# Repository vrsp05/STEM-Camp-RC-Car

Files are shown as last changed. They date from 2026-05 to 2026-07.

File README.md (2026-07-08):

# BYU STEM Camp RC Car

## About This Project

Built by Victor Santana, Jaime Mejia, and Dan Barry as a proposed 2026 workshop for the BYU STEM Camp, this project delivers a robust, low-cost, and low-latency RC car framework. It transforms a standard ESP32-CAM into a standalone web server, video streamer, and motor controller, all without requiring an external internet connection. This interactive experience is designed to inspire students and provide hands-on learning in embedded systems, IoT technology, microcontrollers, and real-time wireless networking.

## Features

* **Low-Latency Video:** Optimized firmware utilizing CIF (400x296) resolution and an adjusted 10MHz clock speed for good MJPEG streaming over a local network.
* **WebSocket System:** Fast response times for driving controls and camera tuning, ensuring the car reacts to your steering instantly.
* **Frictionless Connectivity:** Auto-broadcasting, password-free Wi-Fi Access Points (e.g., `BYU-Car-1`). Students connect and drive instantly.
* **On-the-Fly Tuning:** A sleek, mobile-friendly web dashboard featuring a D-Pad and live sliders to control Headlight brightness, Camera Contrast, and Exposure.

## The Map (How is it organized?)

The repository is organized into four top-level folders to separate documentation, firmware, physical parts, and the web dashboard:

```text
STEM-CAMP-RC-CAR/
├── docs/              # user guides, lesson plans, and troubleshooting
├── firmware/          # ESP32/Arduino source code, configs, and builds
├── hardware/          # 3D-print STL, PCB files, schematics, and BOM
└── web_interface/     # dashboard UI (HTML/CSS/JS) and client assets
```

- **docs/**: Step‑by‑step manuals, programming guides, setup instructions, classroom materials, and troubleshooting notes to build and operate the car.
- **firmware/**: All source code and build artifacts for the ESP32 firmware (sketches, header/config files, build scripts, and CI files). Flashable binaries and board configuration live here.
- **hardware/**: CAD and STL files for 3D printing, PCB design and Gerber/board files, circuit schematics, wiring diagrams, and the bill of materials (BOM).
- **web_interface/**: The mobile‑friendly dashboard — HTML, CSS, JavaScript, assets, and client‑side WebSocket code used to view live video and control the car from a browser or phone.

## The Shopping List (Hardware Requirements)

To build this car, you will need a mix of custom parts and standard robotics electronics. Here is the detailed breakdown:

| Component | Quantity | Purchase Link |
| :--- | :--- | :--- |
| **ESP32-CAM (OV2640 camera)** | 1 | [DigiKey](https://www.digikey.com/short/w14d0qp4) |
| **DRV8833 Motor Controller** | 1 | [Amazon](https://a.co/d/00hcKW4g) |
| **8-Pin Female-to-Male Headers** | 2 | [DigiKey](https://www.digikey.com/short/5r3mm5rb) |
| **6-Pin Male-to-Male Headers** | 1 | [DigiKey](https://www.digikey.com/short/bth0dmv4) |
| **TT DC Gearbox Motors** | 4 | [Amazon](https://a.co/d/0djxPo1a) |
| **Rubber Wheels (for TT Motors)** | 4 | [Amazon](https://a.co/d/0djxPo1a) |
| **T-Brackets** | 4 | [/3d_prints/](hardware/3d_prints/T-Bracket_Mount.stl) |
| **Camera Mount** | 1 | [/3d_prints/](hardware/3d_prints/Camera_Mount.stl) |
| **Headlight Mount** | 1 | [/3d_prints/](/hardware/3d_prints/) |
| **6-32 x 1/4" Mounting Screws** | 8 | [Amazon](https://a.co/d/0eqBX8dm) |
| **Custom PCB Chassis** | 1 | [/electronics/](/hardware/electronics/RC_Car_PCB_v4.zip) |
| **4-AA Battery Holder** | 1 | [DigiKey](https://www.digikey.com/short/vzvpw4tr) |
| **Power Switch (SLW-1276864-4A-D)** | 1 | [DigiKey](https://www.digikey.com/short/3592nqjh) |
| **AA Batteries** | 4 | [Amazon](https://a.co/d/0iRKMYl3) |
| **Zip Tie** | 1 | [Amazon](https://a.co/d/0diwe9JH) |
| **Small Foam / Cardboard Rectangle** | 1 | [Amazon](https://a.co/d/09obGXU5) |

**Total estimated price:** $50-$80

## The Instructions (How do I build it?)

To build, program, and drive your car, you just need to download this repository and follow the step-by-step guides. You do not need to figure out how to build it from scratch, everything is already mapped out for you:

**Step 1: Download the Files (Fork and Clone)**

Before doing anything, you need to save a copy of all these project files to your own computer.

   * Click the **Fork** button at the top right of this GitHub page. This creates a safe copy in your own account so you can make changes without breaking the original project.
   * Open your computer's terminal and clone your new copy by typing:
      ```bash
      git clone https://github.com/vrsp05/STEM-Camp-RC-Car.git

      cd STEM-Camp-RC-Car
      ```

**Step 2: Set Up Your Computer**

   * **File:** [environment_setup.md](/docs/environment/environment_setup.md)
   * **What it does:** This guide shows you exactly how to install the Arduino IDE on your computer, add the ESP32 chip definitions, and make sure your computer can talk to the car's brain over a USB cable.

**Step 3: Assemble the Hardware**

   * **File:** [assembly_guide.pdf](/docs/assembly_docs/assembly_guide.pdf)
   * **What it does:** This is your physical instruction manual. It has clear pictures and step-by-step directions showing you how to solder the electronics to the custom PCB chassis, mount the four yellow gearbox motors using your screws, and attach the wheels.

**Step 4: Program the Brain**

   * **File:** [programming_guide.md](/docs/programming/programming_instructions.md)
   * **What it does:** This guide teaches you how to open the code, give your car a unique Wi-Fi network name, and safely flash the firmware onto the ESP32-CAM using the correct settings so it is ready to drive.

## Credits

**Hardware & Custom PCB Design:**
- **Dan Barry** and **Jaime Mejia** for engineering the custom PCB and assembling the physical hardware of the car.

**Software & Inspiration:**
This project builds upon excellent educational resources from the community:
- [ESP32-CAM Streaming with Motor Control](https://www.youtube.com/watch?v=7I4SnUXxUR0&t=2s) by Jeevan Jee
- [Simple Circuits Tutorial](https://www.youtube.com/watch?v=Du1UvHnD-ZM) by Simple Circuits
- [ESP32-CAM Car Robot Web Server](https://randomnerdtutorials.com/esp32-cam-car-robot-web-server/) by Random Nerd Tutorials
- [RoboArmy Project](https://youtu.be/YqQc_Sm9vlA) by RoboArmy

---

Developed for the BYU STEM Camp (2026).

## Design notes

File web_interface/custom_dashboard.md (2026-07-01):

# Customizing the Dashboard

If you want to customize the look of your car's driving dashboard (change colors, adjust button sizes, or add new controls), do **not** edit the C++ files directly right away!

Inside this repository, you will find a folder called `web_interface` containing an `index.html` file. This is your **UI Sandbox**. Because the structure (HTML) and the styling (CSS) are both inside this single file, testing new designs is incredibly easy.

## How to Test and Save Your Changes

1. **Open the Sandbox:** Double-click `index.html` to open it in your web browser. 
2. **Edit the Code:** Open the exact same file in any text editor (like VS Code or Notepad) and make your changes.
3. **Test Instantly:** Refresh your web browser to see your changes instantly. *(Note: You will not see the live video feed yet, but you will see all your new colors and buttons!)*
4. **Copy Your Work:** Once your new dashboard looks perfect, select everything and copy the entire contents of your customized `index.html` file.
5. **Flash to the Car:** Open `firmware/rc_car_main/index.h` and carefully paste your new code inside the raw string literal to permanently flash it to the car.

## 3 Fun Challenges to Try

Before you copy your final code over to the car, try completing these three challenges inside your `index.html` file!

### Challenge 1: Change the Background Color
Right now, the dashboard has a dark blue background. Let's make it your favorite color!
* Look inside the `<style>` section near the top of the file.
* Find the line that starts with `body { background-color: var(--byu-blue);`. 
* Change `var(--byu-blue)` to a simple color name like `black`, `green`, or `orange`. Save the file and refresh your browser!

### Challenge 2: Change the Button Symbols to Words
Right now, the driving buttons use shapes like ▲ and ■. Want to make them say words instead? 
* Scroll down past the styles until you find the HTML code for the buttons (look for lines like `<button id="btn-fwd">▲</button>`).
* Delete the ▲ symbol and type in a word like "FORWARD" or "GAS". Save the file and refresh your browser.

### Challenge 3: Make the D-Pad Bigger
If the steering buttons are too small for your thumbs, you can scale them up!
* Go back up to the `<style>` section and look for the `.controls button {` line. 
* Find `padding: 20px 0;` and change the `20` to `35`.
* Find `font-size: 1.2em;` and change the `1.2` to `2.0`. 
* Save your file, and see how your giant buttons look on the screen!

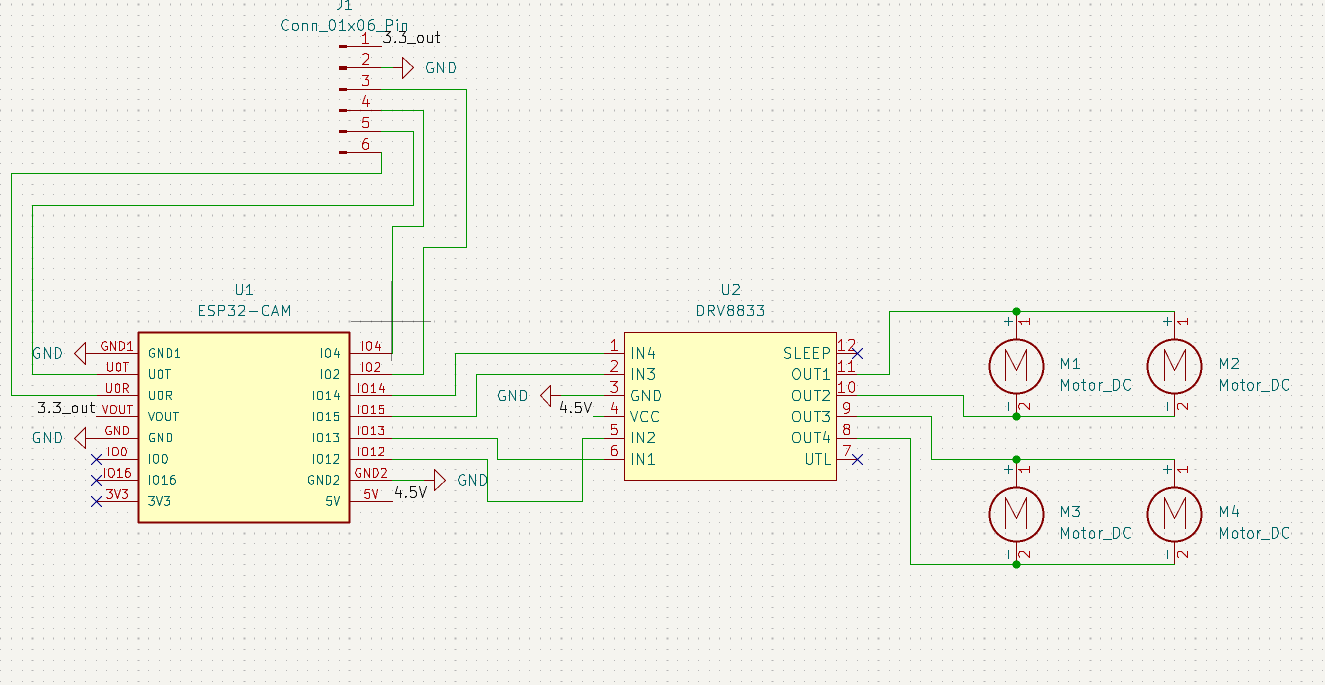
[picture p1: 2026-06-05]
hardware/electronics/STEM Camp RC Car Schematic.png

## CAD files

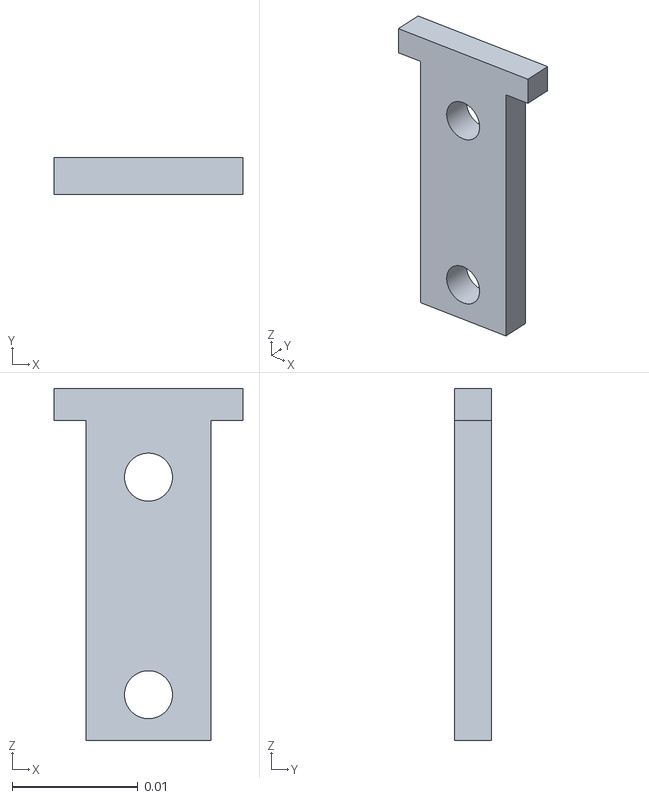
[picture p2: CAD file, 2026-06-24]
hardware/3d_prints/T-Bracket_Mount.stl
0.015 x 0.00292 x 0.0279

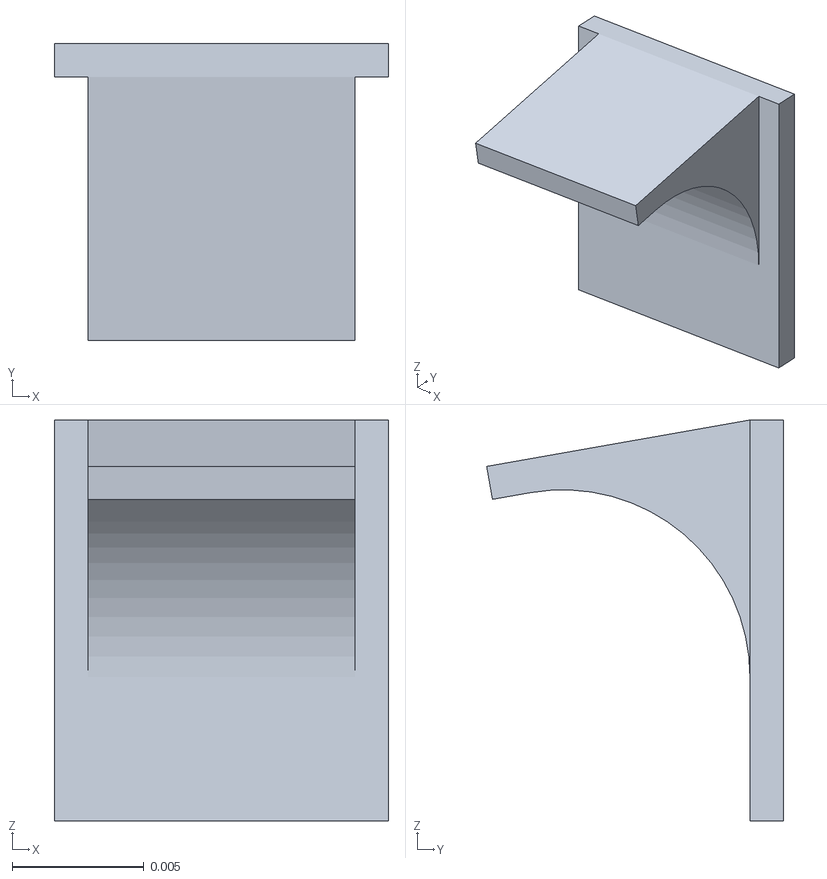
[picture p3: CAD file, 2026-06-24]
hardware/3d_prints/Camera_Mount.stl
0.0127 x 0.0113 x 0.0152

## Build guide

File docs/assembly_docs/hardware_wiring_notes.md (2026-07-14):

# Hardware & Wiring Notes

If you are building the car using the custom STEM Camp PCB, this guide explains exactly how the electronics connect and the number one physical mistake to avoid when building your drivetrain.

## Wiring Guide

The custom PCB handles all the complicated power routing for you, but it is helpful to know exactly how the car's brain talks to the wheels. The ESP32-CAM sends signals to the motor controller using these specific pins:

* **Left Motors (Channel A):** Controlled by GPIO 14 and GPIO 15
* **Right Motors (Channel B):** Controlled by GPIO 13 and GPIO 12
* **Camera LED Flashlight:** Controlled by GPIO 4

## Crucial Assembly Warning: The "Mirror Effect"

When you build a 4-wheel drive car, you have front motors and back motors. Because of how they fit into the plastic frame, the front and back motors are physically facing opposite directions. They are "mirrored."

**The Problem:** If you solder the wires to the front motors and the back motors exactly the same way, the front wheels will spin forward, but the back wheels will spin backward. The car will fight against itself and will not move properly.

**The Fix:** You must solder the wires on the back motors "backwards" compared to the front motors so all four wheels push in the exact same direction. 

* If your **Front** motors (M1 & M3) have the **Red** wire on the + pin and the **Black** wire on the - pin.
* Your **Back** motors (M2 & M4) must have the **Black** wire on the + pin and the **Red** wire on the - pin. 

Always double-check your motor wiring before you screw the chassis completely together!

## Hardware Quirks: Motor Speeds

Not all yellow TT motors are created equal! If one of your cars is much faster than the others, check the motor colors. 

* **Dull Yellow Motors:** These typically have a **1:48 gear ratio**. They are built for high speed. 
* **Bright Yellow Motors:** These typically have a **1:120 gear ratio**. They are built for heavy pushing power and will drive much slower. 

Always try to match the exact same motor colors when building a single car. If you mix a dull yellow motor with a bright yellow motor, your car will constantly pull to one side and will not drive straight!

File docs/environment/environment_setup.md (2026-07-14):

# Setting Up Your Environment

Before we can teach the car how to drive, we need to teach your computer how to talk to the car's brain. To do this, we use a free program called the **Arduino IDE**.

## What You Need (Prerequisites)

Before opening any programs, make sure you have these items ready on your desk:

* **The Free Software:** Download and install the [Arduino IDE](https://www.arduino.cc/en/software) on your computer.
* **The Car's Brain:** Your ESP32-CAM board with the tiny camera attached.
* **The USB Adapter:** The ESP32-CAM cannot plug directly into a computer. You must plug it into the small USB programmer board (the motherboard "MB" adapter shield) first.
* **A Data-Sync USB Cable:** This is incredibly important. Many phone charger cables only provide power and cannot send data. You *must* use a cable that supports data transfer, or your computer will never see the ESP32.

## Step 1: Install ESP32 Board Support

1. Open the **Arduino IDE**.
2. Go to **Tools → Board → Boards Manager**.
3. Search for `ESP32` in the search box.
4. Find **"esp32 by Espressif Systems"** and select the **latest version**.
5. Click the **Install** button and wait for the installation to complete.

## Step 2: Download the Remote Control Dictionary (WebSockets)

The ESP32 dictionary we just installed knows how to use basic Wi-Fi, but it doesn't know how to connect to our custom digital steering wheel. We need to download a library to fix that.

1. **Open the Library Manager:** In the Arduino IDE, click on **Sketch** at the top of the screen, hover over **Include Library**, and click **Manage Libraries...** (You can also just click the little icon that looks like a stack of books on the left side of your screen).
2. **Search for WebSockets:** In the search bar of the new menu, type in exactly `WebSockets` and hit Enter.
3. **Find the Right Author:** Scroll through the list until you find the library named exactly **WebSockets**. Look closely at the small text underneath the title—it **must** say **by Markus Sattler**.
4. **Install It:** Select the latest version and click the **Install** button next to it. Once it says "Installed," you can close the Library Manager menu.

## Step 3: Tell the Computer Which Brain You Have

The dictionary we just downloaded is huge. It contains instructions for hundreds of different ESP32 chips! We need to tell the computer exactly which one you are holding in your hand.

1. **Open the Board Menu:** At the top of your screen, click on **Tools**, hover over **Board**, and then hover over the new **esp32** folder you just installed.
2. **Find the AI Thinker:** A massive list of boards will pop out. Scroll down through this list until you find the one named exactly **"AI Thinker ESP32-CAM"**.
3. **Select It:** Click on it! 

*Pro-Tip: You can double-check that you did it right by looking at the top left corner of your Arduino window. It should now say "AI Thinker ESP32-CAM".*

## Step 4: Pick the Right USB Door (Select the COM Port)

Your computer has several USB plugs, and it doesn't automatically know which one is holding the car's brain. We need to point it to the right "door" so they can talk.

1. **Plug It In:** Connect your ESP32-CAM (attached to its small programmer board) to your computer using your data-sync USB cable.
2. **Open the Menu:** In the Arduino program, click on **Tools** at the top of the screen.
3. **Find the Port:** Look down the menu list and hover over **Port**. 
4. **Select the Connection:** You should see an option pop up. If you are on Windows, it will look like `COM3` (or a higher number). If you are on a Mac, it will look like `/dev/cu.usbserial-....`. Click on it! 

*Pro-Tip: If you have a bunch of different ports listed and don't know which one is your car, or if the "Port" button is completely grayed out, don't panic! Check the **How to Find Your Port** section right below this to play detective.*

---

### How to Find Your Port (Windows & Mac)

If you are completely stuck on Step 3, you can use your computer's built-in tools to figure out exactly which port your car is plugged into.

**For Windows (Device Manager):**
1. Click the Windows Start button at the bottom of your screen, type **Device Manager**, and hit Enter.
2. Look down the list for a category called **Ports (COM & LPT)** and click the little arrow next to it to open it up.
3. You are looking for a device that says **USB-SERIAL CH340**, **CP210x**, or something similar.
4. Look at the number right next to it in parentheses (for example, `COM4`). That is your port number. Go back to the Arduino IDE and select that exact port.

**For Mac (System Report):**
1. Click the **Apple logo** in the very top left corner of your screen.
2. Click **About This Mac**, then click **More Info...**, and finally scroll down and click **System Report...**.
3. On the left side of the new window, look under the "Hardware" section and click on **USB**.
4. Look through the USB Device Tree for something named **USB to UART Bridge** or **CH340**. If you see it there, your computer successfully sees the car! Go back to the Arduino program and select the port that starts with `/dev/cu.usbserial`.

*(Note: If you do not see the device in your Windows Device Manager or your Mac System Report, your USB cable is likely a "charge-only" cable. Swap it out for a real data cable and try again!)*

---

**You Did It!**
Your computer is now fully set up and ready to code. You can close this guide, return to the **[main README](../../README.md)**, and follow the next steps to flash the brain and start driving!

## Troubleshooting (What if it doesn't work?)

Don't panic! Even professional engineers run into errors. Here is how to fix the most common computer bugs:

### 1. "My Port is Not Showing Up!"
* **The Cable Test:** 99% of the time, this happens because you are using a "charge-only" USB cable instead of a "data" cable. Try swapping out the cable!
* **The Connection Test:** Make sure the ESP32-CAM is pushed down firmly into the small programmer board.

### 2. "The Upload Keeps Failing!"
* **Check Your Brain:** Go back to **Tools > Board** and make absolutely sure you selected **"AI Thinker ESP32-CAM"**. 
* **The BOOT Button Trick:** Sometimes the brain is stubborn and won't accept the new code. While the code is uploading, physically press and hold the **BOOT** (or **IO0**) button on the small programmer board. This forces the chip to wake up and listen to the computer!

*(Note: It's also possible that you may have purchased a defective or low-quality ESP32. We recommend buying from DigiKey or other trustworthy sellers.)*

### 3. "My Camera Screen is Blank!"
* **The Ribbon Snap:** Check the tiny ribbon cable connecting the camera to the board. It needs to be pushed all the way in and locked down safely.
* **The MicroSD Trap:** If you have a little memory card (MicroSD card) plugged into the back of the ESP32-CAM, take it out! It completely blocks the live video from working.

*(Note: It's also possible that you may have purchased a defective or low-quality ESP32. We recommend buying from DigiKey or other trustworthy sellers.)*

### 4. "fatal error: WebSocketsServer.h: No such file or directory"
* **The Missing Library Error:** The computer is trying to build the remote control connection, but it doesn't have the instructions. Go back to **Step 2** and make absolutely sure you installed the **WebSockets by Markus Sattler** library using the Library Manager.

### 5. "The Upload Keeps Crashing / Hidden Baud Rate"
* **The Dev Module Trick:** Sometimes the computer tries to send the code too fast, which causes a crash. If you need to lower the upload speed (baud rate) but the Arduino IDE hides that option when you select the AI Thinker board, you can outsmart it. Change your board to **"ESP32 Dev Module"**. This is a generic profile that unlocks the hidden menus. Change your **Upload Speed** to **115200**, make sure **PSRAM** is **Enabled**, and try uploading again.

*(Note: It's also possible that you may have purchased a defective or low-quality ESP32. We recommend buying from DigiKey or other trustworthy sellers.)*

### 6. Still Stuck?
* **Ask an AI Helper:** If the Arduino program spits out a crazy red error message, you can copy that text and paste it into ChatGPT, Claude, or GitHub Copilot. Just ask the AI, "How do I fix this Arduino error?" and it will help translate the computer gibberish for you!

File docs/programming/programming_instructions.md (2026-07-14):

# BYU STEM Camp RC Car: Programming Guide

Welcome to the final step of your RC Car build. Right now, your car is just plastic, motors, and wires. In this guide, we are going to give it a brain.

The tiny computer on your car (called the ESP32-CAM) is incredibly special. It does not just hold code, it actually creates its very own Wi-Fi network! 

Here is how the magic works:
1. **The Code:** We will upload a file that teaches the brain how to drive.
2. **The Wi-Fi:** The brain will create a private Wi-Fi network just for your car.
3. **The Connection:** You will connect your phone to that network, turning your phone into the steering wheel and the video screen.

Let's get your car programmed and ready to race!

## Step-by-Step Setup

### 1. Name Your Car & Pick a Wi-Fi Channel

Before we put the brain into the car, we need to give it a unique identity. If all the cars in the room have the exact same Wi-Fi name, your phone will not know which one is yours, and you might accidentally connect to your friend's car.

We also need to pick a Wi-Fi **Channel**. Think of a channel like a lane on an invisible highway. If every single car in the camp tries to drive in the exact same lane, there will be a massive traffic jam and your live video may freeze. 

Here is exactly how to change your car's name and pick your highway lane in the code:

1. **Open the Code:** Open the Arduino IDE on your computer. Click **File > Open**, and open the main code file located inside your `firmware/rc_car_main` folder called `rc_car_main.ino`. 
2. **Find the Wi-Fi Name:** Scroll down near the top of the code until you see a line that sets the network name. It will look something like this:
   `const char *carSSID = "BYU-Car-0";`
3. **Change the Name:** Delete the words inside the quotation marks and type in your own custom name (for example: `"BYU-Car-1"` or `"Lightning"`). *Warning: Make sure you do not delete the quotation marks!*
4. **Find the Channel:** Right below your name, look for the line that sets the Wi-Fi channel. It will look something like this:
   `const int wifiChannel = 1;`
5. **Pick Your Lane:** Change that number to **1**, **6**, or **11**. These three numbers are the best "fast lanes" for Wi-Fi. *(Pro-Tip: Ask other next to you which number they picked, and try to choose a different one so your cars do not share the same lane.)*

### 2. Flash the Firmware (Upload the Brain)

Now that you have chosen a name and a lane, it is time to transfer the code from your computer into the ESP32-CAM. We call this "flashing" the firmware. 

1. **Remove the Brain:** Before you plug anything in, you MUST unplug the ESP32-CAM from the car's main circuit board.
2. **Plug it In:** Connect the ESP32-CAM to its motherboard and then to your computer using a USB cable. 
3. **Pick the Right Brain:** In the Arduino program, click on **Tools > Board** and select **"AI Thinker ESP32-CAM"**.
4. **Pick the Right Cable:** Click on **Tools > Port** and select the COM port that shows up (this tells the computer which USB plug you are using).
5. **Click Upload:** Click the round **Right Arrow (Upload)** button at the top left of your screen. 

Watch the black box at the bottom of the screen. When the text stops moving and it says **"Done Uploading"** (or something similar), your car's brain is officially programmed.

### 3. Power On and Connect (Wake Up the Car)

Now that the brain is programmed, it is time to cut the cord and let the car wake up on its own!

1. **Unplug the Cable:** Carefully unplug the USB cable from the car's brain. You don't need the computer anymore. Now plug the ESP32 back into the car.
2. **Turn on the Batteries:** Make sure you have 4 AA batteries in the holder, and flip the main power switch on the car to the **ON** position. 
3. **Find Your Network:** Open the Wi-Fi settings on your smartphone (or a tablet).
4. **Connect to Your Car:** Look at the list of Wi-Fi networks and tap on the custom name you created in Step 1 (like "BYU-Car-1"). 

*Note: Your car's network does not have a password, so it will connect instantly. Your phone might pop up a warning saying "No Internet Connection." Do not worry—that is exactly what is supposed to happen because your car is not a normal Wi-Fi router.*

### 4. Launch the Dashboard (Take the Wheel)

You are connected! Now it is time to open your digital steering wheel and see through the car's eyes.

1. **Open a Browser:** Open a web browser on your phone or computer (like Safari, Chrome, or Edge).
2. **Type the Secret Address:** Tap on the search bar at the very top of your screen, type in exactly **192.168.4.1**, and hit Enter. 
3. **Start Driving:** The screen will load your custom dashboard. You should immediately see a live video feed from the front of your car. Use the D-pad buttons to steer, and play with the sliders to turn on your headlights!

## Using the Web Interface

Once the dashboard loads, you will have full control over the car's hardware. Here is what each section of the interface does:

- **Live Video Feed:** The screen at the top displays the real-time camera stream.
- **Directional Pad (D-Pad):** These are your driving controls. Press the top, bottom, left, and right arrows to move the car. The square button in the center acts as the brake to stop the motors.
- **Headlights Slider:** This controls the physical LED flash on the front of the ESP32-CAM. Sliding it to the right increases the brightness so you can navigate in dark environments.
- **Brightness Slider:** This is a software control that adjusts the camera sensor's exposure. If your video feed is too dark or washed out by the sun, adjust this slider to let more or less digital light into the lens.
- **Contrast Slider:** This modifies the difference between the light and dark areas of the video feed. Increasing the contrast can help make edges and obstacles look sharper and more defined on your screen.

## Keep Hacking at Home

The best part of engineering is breaking things and making them your own. If you want to see exactly how this code works or start modifying the dashboard and motor controls yourself, you can find the complete source code online.

Go to the [firmware/rc_car_main](/firmware/rc_car_main/) folder to view the code. Be sure to fork the repository to your own account so you can start making your own changes and improvements!

## Troubleshooting & Pro-Tips

### 1. Code Upload Issues

* **The Missing COM Port:** If you connect your board to the computer but do not see a COM port listed, you are likely using a "charge-only" USB cable. Swap it out for a cable that supports data transfer to fix the issue.
* **The Antenna Effect (Flashing Crash):** If your upload crashes with an `exit status 2` error, your car's body is causing interference. You must completely remove the ESP32-CAM from the custom car PCB before flashing. If it is plugged in, the copper lines on the board act like antennas and scramble the data transfer.
* **The "Hidden" Upload Speed:** If the Arduino IDE hides the "Upload Speed" option when you select the AI Thinker board, you can outsmart it! Change your board to **ESP32 Dev Module**. This generic profile unlocks the hidden menu. Set your Upload Speed to **115200**, change **PSRAM** to **Enabled**, and hit upload. This prevents the high-speed crashing issue.
* **The "Upload Fails" Timeout:** If your upload hangs or fails to connect, ensure you have the "AI Thinker ESP32-CAM" selected as your board. If it still fails, you can physically force the connection by pressing and holding the **I0O** button on your programmer board while the code is uploading.

### 2. Video & Camera Issues

* **Camera Not Working (Blank Screen):** If the dashboard loads but you have no video, first verify that the tiny OV2640 camera ribbon is snapped completely into its connector. Second, ensure there is absolutely no MicroSD card inserted into the board.
* **Hardware Warning (The "Blind Car"):** Sometimes, cheap or low-quality ESP32-CAM boards will connect and drive perfectly, but the video will just refuse to show up no matter what you do. To prevent this, we highly recommend buying your ESP32-CAM boards from trusted, high-quality manufacturers.

### 3. Wi-Fi & Driving Connection (Phone to Car)

* **Video Freezing or Losing Control:** If the live video feed suddenly stops or the car stops responding to your controls, you have likely driven out of the ESP32's Wi-Fi range. Try these steps to fix it:
  1. **Get Closer:** Walk back toward the car so your phone is within a clear line of sight, and refresh the web page.
  2. **Restart the Wi-Fi:** Turn the Wi-Fi off and then back on in your phone or computer settings, then reconnect to your car's network.
  3. **Restart the Car:** Turn the car's power off, wait a few seconds, and turn it back on. Reconnect your phone to the network and reload the dashboard.

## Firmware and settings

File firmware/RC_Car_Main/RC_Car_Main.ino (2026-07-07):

#include <Arduino.h>
#include "esp_camera.h"
#include <WiFi.h>
#include <WebSocketsServer.h>
#include <index.h>

// Initiate WebSocketServer using Port #82
WebSocketsServer webSocket = WebSocketsServer(82);

// ===========================
// Select camera model in board_config.h
// ===========================
#include "board_config.h"

// ===========================
// Hardcoded Factory Credentials
// Change this number for each car before flashing! (e.g., BYU-Car-2, BYU-Car-3)
// ===========================
const char *carSSID = "general182";

// ===========================
// Wi-Fi Channel Selection
// Use ONLY channels 1, 6, or 11 to prevent cars from lagging each other.
// Distribute evenly: e.g., Cars 1-3 on Ch 1, Cars 4-6 on Ch 6, Cars 7-10 on Ch 11.
// ===========================
const int wifiChannel = 1;

// ===========================
// Motor Driver Blueprint
// ===========================
struct MOTOR_PINS {
  int pinIN1;
  int pinIN2;
};

// ===========================
// Motor Pin Definitions
// ===========================

// Right Motor Channel (M1 & M2) -> Pins 13 & 12
MOTOR_PINS rightMotor = {13, 12}; 

// Left Motor Channel (M3 & M4) -> Pins 15 & 14
MOTOR_PINS leftMotor = {15, 14};

// ===========================
// Software Speed Governor
// ===========================
int maxSpeed = 150; // Scale from 0 (Stop) to 255 (Full Throttle). 150 is a safe indoor speed.

// ===========================
// Movement Functions (PWM Upgraded)
// ===========================
void stopCar() {
  ledcWrite(rightMotor.pinIN1, 0);
  ledcWrite(rightMotor.pinIN2, 0);
  ledcWrite(leftMotor.pinIN1, 0);
  ledcWrite(leftMotor.pinIN2, 0);
  Serial.println("Car: STOP");
}

void driveForward() {
  // Right side (M1 & M2) pushes forward
  ledcWrite(rightMotor.pinIN1, maxSpeed);
  ledcWrite(rightMotor.pinIN2, 0);
  
  // Left side (M3 & M4) pushes forward
  ledcWrite(leftMotor.pinIN1, maxSpeed);
  ledcWrite(leftMotor.pinIN2, 0);
  
  Serial.println("Car: FORWARD (Normal)");
}

void driveBackward() {
  ledcWrite(rightMotor.pinIN1, 0);
  ledcWrite(rightMotor.pinIN2, maxSpeed);
  ledcWrite(leftMotor.pinIN1, 0);
  ledcWrite(leftMotor.pinIN2, maxSpeed);
  Serial.println("Car: BACKWARD");
}

void turnRight() {
  ledcWrite(rightMotor.pinIN1, 0);
  ledcWrite(rightMotor.pinIN2, maxSpeed);
  ledcWrite(leftMotor.pinIN1, maxSpeed);
  ledcWrite(leftMotor.pinIN2, 0);
  Serial.println("Car: RIGHT");
}

void turnLeft() {
  ledcWrite(rightMotor.pinIN1, maxSpeed);
  ledcWrite(rightMotor.pinIN2, 0);
  ledcWrite(leftMotor.pinIN1, 0);
  ledcWrite(leftMotor.pinIN2, maxSpeed);
  Serial.println("Car: LEFT");
}

void startCameraServer();
void setupLedFlash();

// ===========================
// WebSocket Client Lock
// ===========================
int activeClient = -1; // -1 means the car is currently available

void webSocketEvent(uint8_t num, WStype_t type, uint8_t *payload, size_t length) {
  
  // 1. Handle Disconnections
  if (type == WStype_DISCONNECTED) {
    if (activeClient == num) {
      Serial.println("Driver disconnected. Car is now available.");
      activeClient = -1; // Free up the lock for the next student
      stopCar();         // SAFETY FEATURE: Hit the brakes if Wi-Fi drops!
    }
  } 
  
  // 2. Handle New Connections
  else if (type == WStype_CONNECTED) {
    if (activeClient == -1) {
      activeClient = num; // Claim the lock
      Serial.printf("Phone [%u] Connected! Car locked.\n", num);
    } else {
      Serial.printf("Phone [%u] rejected. Car is already in use.\n", num);
      // Send an alert string to the rejected phone before dropping them
      webSocket.sendTXT(num, "ERROR: Car is currently in use by another student.");
      webSocket.disconnect(num); // Kick the intruder off the server
    }
  } 
  
  // 3. Handle Driving Commands
  else if (type == WStype_TEXT) {
    // SECURITY CHECK: Ignore commands from anyone who isn't the active driver
    if (num != activeClient) return; 

    String command = String((char*)payload);
    Serial.print("Phone sent command: ");
    Serial.println(command);

    int sepIndex = command.indexOf(':');
    
    // ==========================================
    // TYPE 1: SLIDER COMMANDS (Contains a ':')
    // ==========================================
    if (sepIndex > 0) { 
      String cmdName = command.substring(0, sepIndex);
      int cmdValue = command.substring(sepIndex + 1).toInt();
      
      if (cmdName == "led") {
        int safeValue = map(cmdValue, 0, 255, 0, 40); 
        ledcWrite(4, safeValue); 
      }
      else if (cmdName == "bright") {
        sensor_t * s = esp_camera_sensor_get();
        s->set_brightness(s, cmdValue);
      }
      else if (cmdName == "contrast") {
        sensor_t * s = esp_camera_sensor_get();
        s->set_contrast(s, cmdValue);
      }
    }
    // ==========================================
    // TYPE 2: BUTTON COMMANDS (No ':')
    // ==========================================
    else { 
      if (command == "forward") {
        driveForward();
      }
      else if (command == "backward") {
        driveBackward();
      }
      else if (command == "left") {
        turnLeft();
      }
      else if (command == "right") {
        turnRight();
      }
      else if (command == "stop") {
        stopCar();
      }
    }
  }
}

void setup() {
  Serial.begin(115200);
  Serial.setDebugOutput(true);
  Serial.println();

  camera_config_t config;
  config.ledc_channel = LEDC_CHANNEL_0;
  config.ledc_timer = LEDC_TIMER_0;
  config.pin_d0 = Y2_GPIO_NUM;
  config.pin_d1 = Y3_GPIO_NUM;
  config.pin_d2 = Y4_GPIO_NUM;
  config.pin_d3 = Y5_GPIO_NUM;
  config.pin_d4 = Y6_GPIO_NUM;
  config.pin_d5 = Y7_GPIO_NUM;
  config.pin_d6 = Y8_GPIO_NUM;
  config.pin_d7 = Y9_GPIO_NUM;
  config.pin_xclk = XCLK_GPIO_NUM;
  config.pin_pclk = PCLK_GPIO_NUM;
  config.pin_vsync = VSYNC_GPIO_NUM;
  config.pin_href = HREF_GPIO_NUM;
  config.pin_sccb_sda = SIOD_GPIO_NUM;
  config.pin_sccb_scl = SIOC_GPIO_NUM;
  config.pin_pwdn = PWDN_GPIO_NUM;
  config.pin_reset = RESET_GPIO_NUM;
  
  // --- STABILITY TUNE ---
  // 1. Clock Speed: Dropped from 20MHz to 10MHz to prevent hardware crashing
  config.xclk_freq_hz = 10000000; 
  
  // 2. Resolution: Bumped to CIF (400x296) for better quality without lagging the D-Pad
  config.frame_size = FRAMESIZE_CIF; 
  
  config.pixel_format = PIXFORMAT_JPEG;
  config.grab_mode = CAMERA_GRAB_LATEST;
  config.fb_location = CAMERA_FB_IN_PSRAM;
  
  // 3. JPEG Quality: Lowered to 12 for a sharper image (lower number = less compression)
  config.jpeg_quality = 12; 
  config.fb_count = 2;

  // Fallback if the chip has bad memory
  if (!psramFound()) {
    config.frame_size = FRAMESIZE_QVGA;
    config.fb_location = CAMERA_FB_IN_DRAM;
    config.fb_count = 1;
  }

  // camera init
  esp_err_t err = esp_camera_init(&config);
  if (err != ESP_OK) {
    Serial.printf("Camera init failed with error 0x%x", err);
    return;
  }

  // Initialize motor pins as PWM speed outputs (1000 Hz, 8-bit resolution)
  ledcAttach(rightMotor.pinIN1, 1000, 8);
  ledcAttach(rightMotor.pinIN2, 1000, 8);
  ledcAttach(leftMotor.pinIN1, 1000, 8);
  ledcAttach(leftMotor.pinIN2, 1000, 8);
  
  // Ensure the car starts in a parked state
  stopCar();

  sensor_t *s = esp_camera_sensor_get();

  // --- THE AUTO-PILOT TUNE ---
  s->set_exposure_ctrl(s, 1); // Auto-Exposure ON (adapts to shadows/sunlight)
  s->set_aec2(s, 1);          // Advanced Auto-Exposure DSP ON
  s->set_whitebal(s, 1);      // Auto-White Balance ON (removes weird color tints)
  s->set_awb_gain(s, 1);      // Auto-White Balance Gain ON
  s->set_wb_mode(s, 0);       // Set White Balance Mode to standard Auto

// Setup LED FLash if LED pin is defined in camera_pins.h
#if defined(LED_GPIO_NUM)
  setupLedFlash();
#endif

  // --- Open Access Point (No Password) ---
  // Using NULL creates an open network. wifiChannel locks the broadcast frequency.
  WiFi.softAP(carSSID, NULL, wifiChannel);
  Serial.println("");
  Serial.println("Car Wi-Fi Network Started!");

  // --- BOOT FLASH ---
  // Blink the LED 3 times quickly at a safe brightness to signal the car is ready
  for(int i = 0; i < 3; i++) {
    ledcWrite(4, 25); 
    delay(150);
    ledcWrite(4, 0);   
    delay(150);
  }

  startCameraServer();

  // Initialize the Flash LED (Pin 4) for smooth brightness control (ESP32 Core v3.x)
  ledcAttach(4, 1000, 8); // Attach Pin 4, 1000 Hz, 8-bit (0-255)
  ledcWrite(4, 0);        // Start with the headlights OFF
  
  // Initialize the webSocket
  webSocket.begin();
  webSocket.onEvent(webSocketEvent);

  Serial.print("Camera Ready! Use 'http://");
  Serial.print(WiFi.softAPIP());
  Serial.println("' to connect");
}

void loop() {
  webSocket.loop(); // Constantly check for new commands
  delay(1);         // A tiny pause to keep the brain stable
}

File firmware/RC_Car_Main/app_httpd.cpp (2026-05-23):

// Copyright 2015-2016 Espressif Systems (Shanghai) PTE LTD
//
// Licensed under the Apache License, Version 2.0 (the "License");
// you may not use this file except in compliance with the License.
// You may obtain a copy of the License at
//
//     http://www.apache.org/licenses/LICENSE-2.0
//
// Unless required by applicable law or agreed to in writing, software
// distributed under the License is distributed on an "AS IS" BASIS,
// WITHOUT WARRANTIES OR CONDITIONS OF ANY KIND, either express or implied.
// See the License for the specific language governing permissions and
// limitations under the License.

#include "Arduino.h"
#include "esp_http_server.h"
#include "esp_timer.h"
#include "esp_camera.h"
#include "img_converters.h"
#include "fb_gfx.h"
#include "esp32-hal-ledc.h"
#include "sdkconfig.h"
#include "camera_index.h"
#include "board_config.h"
#include "index.h"

#if defined(ARDUINO_ARCH_ESP32) && defined(CONFIG_ARDUHAL_ESP_LOG)
#include "esp32-hal-log.h"
#endif

// LED FLASH setup
#if defined(LED_GPIO_NUM)
#define CONFIG_LED_MAX_INTENSITY 255

int led_duty = 0;
bool isStreaming = false;

#endif

typedef struct {
  httpd_req_t *req;
  size_t len;
} jpg_chunking_t;

#define PART_BOUNDARY "123456789000000000000987654321"
static const char *_STREAM_CONTENT_TYPE = "multipart/x-mixed-replace;boundary=" PART_BOUNDARY;
static const char *_STREAM_BOUNDARY = "\r\n--" PART_BOUNDARY "\r\n";
static const char *_STREAM_PART = "Content-Type: image/jpeg\r\nContent-Length: %u\r\nX-Timestamp: %d.%06d\r\n\r\n";

httpd_handle_t stream_httpd = NULL;
httpd_handle_t camera_httpd = NULL;

typedef struct {
  size_t size;   //number of values used for filtering
  size_t index;  //current value index
  size_t count;  //value count
  int sum;
  int *values;  //array to be filled with values
} ra_filter_t;

static ra_filter_t ra_filter;

static ra_filter_t *ra_filter_init(ra_filter_t *filter, size_t sample_size) {
  memset(filter, 0, sizeof(ra_filter_t));

  filter->values = (int *)malloc(sample_size * sizeof(int));
  if (!filter->values) {
    return NULL;
  }
  memset(filter->values, 0, sample_size * sizeof(int));

  filter->size = sample_size;
  return filter;
}

#if ARDUHAL_LOG_LEVEL >= ARDUHAL_LOG_LEVEL_INFO
static int ra_filter_run(ra_filter_t *filter, int value) {
  if (!filter->values) {
    return value;
  }
  filter->sum -= filter->values[filter->index];
  filter->values[filter->index] = value;
  filter->sum += filter->values[filter->index];
  filter->index++;
  filter->index = filter->index % filter->size;
  if (filter->count < filter->size) {
    filter->count++;
  }
  return filter->sum / filter->count;
}
#endif

#if defined(LED_GPIO_NUM)
void enable_led(bool en) {  // Turn LED On or Off
  int duty = en ? led_duty : 0;
  if (en && isStreaming && (led_duty > CONFIG_LED_MAX_INTENSITY)) {
    duty = CONFIG_LED_MAX_INTENSITY;
  }
  ledcWrite(LED_GPIO_NUM, duty);
  //ledc_set_duty(CONFIG_LED_LEDC_SPEED_MODE, CONFIG_LED_LEDC_CHANNEL, duty);
  //ledc_update_duty(CONFIG_LED_LEDC_SPEED_MODE, CONFIG_LED_LEDC_CHANNEL);
  log_i("Set LED intensity to %d", duty);
}
#endif

static esp_err_t bmp_handler(httpd_req_t *req) {
  camera_fb_t *fb = NULL;
  esp_err_t res = ESP_OK;
#if ARDUHAL_LOG_LEVEL >= ARDUHAL_LOG_LEVEL_INFO
  int64_t fr_start = esp_timer_get_time();
#endif
  fb = esp_camera_fb_get();
  if (!fb) {
    log_e("Camera capture failed");
    httpd_resp_send_500(req);
    return ESP_FAIL;
  }

  httpd_resp_set_type(req, "image/x-windows-bmp");
  httpd_resp_set_hdr(req, "Content-Disposition", "inline; filename=capture.bmp");
  httpd_resp_set_hdr(req, "Access-Control-Allow-Origin", "*");

  char ts[32];
  // Cast to uint32_t is safe until year 2106.
  snprintf(ts, 32, "%" PRIu32 ".%06" PRIu32, (uint32_t)fb->timestamp.tv_sec, (uint32_t)fb->timestamp.tv_usec);
  httpd_resp_set_hdr(req, "X-Timestamp", (const char *)ts);

  uint8_t *buf = NULL;
  size_t buf_len = 0;
  bool converted = frame2bmp(fb, &buf, &buf_len);
  esp_camera_fb_return(fb);
  if (!converted) {
    log_e("BMP Conversion failed");
    httpd_resp_send_500(req);
    return ESP_FAIL;
  }
  res = httpd_resp_send(req, (const char *)buf, buf_len);
  free(buf);
#if ARDUHAL_LOG_LEVEL >= ARDUHAL_LOG_LEVEL_INFO
  int64_t fr_end = esp_timer_get_time();
#endif
  log_i("BMP: %" PRId32 "ms, %" PRIu32 "B", (int32_t)((fr_end - fr_start) / 1000), (uint32_t)buf_len);
  return res;
}

static size_t jpg_encode_stream(void *arg, size_t index, const void *data, size_t len) {
  jpg_chunking_t *j = (jpg_chunking_t *)arg;
  if (!index) {
    j->len = 0;
  }
  if (httpd_resp_send_chunk(j->req, (const char *)data, len) != ESP_OK) {
    return 0;
  }
  j->len += len;
  return len;
}

static esp_err_t capture_handler(httpd_req_t *req) {
  camera_fb_t *fb = NULL;
  esp_err_t res = ESP_OK;
#if ARDUHAL_LOG_LEVEL >= ARDUHAL_LOG_LEVEL_INFO
  int64_t fr_start = esp_timer_get_time();
#endif

#if defined(LED_GPIO_NUM)
  enable_led(true);
  vTaskDelay(150 / portTICK_PERIOD_MS);  // The LED needs to be turned on ~150ms before the call to esp_camera_fb_get()
  fb = esp_camera_fb_get();              // or it won't be visible in the frame. A better way to do this is needed.
  enable_led(false);
#else
  fb = esp_camera_fb_get();
#endif

  if (!fb) {
    log_e("Camera capture failed");
    httpd_resp_send_500(req);
    return ESP_FAIL;
  }

  httpd_resp_set_type(req, "image/jpeg");
  httpd_resp_set_hdr(req, "Content-Disposition", "inline; filename=capture.jpg");
  httpd_resp_set_hdr(req, "Access-Control-Allow-Origin", "*");

  char ts[32];
  // Cast to uint32_t is safe until year 2106.
  snprintf(ts, 32, "%" PRIu32 ".%06" PRIu32, (uint32_t)fb->timestamp.tv_sec, (uint32_t)fb->timestamp.tv_usec);
  httpd_resp_set_hdr(req, "X-Timestamp", (const char *)ts);

#if ARDUHAL_LOG_LEVEL >= ARDUHAL_LOG_LEVEL_INFO
  size_t fb_len = 0;
#endif
  if (fb->format == PIXFORMAT_JPEG) {
#if ARDUHAL_LOG_LEVEL >= ARDUHAL_LOG_LEVEL_INFO
    fb_len = fb->len;
#endif
    res = httpd_resp_send(req, (const char *)fb->buf, fb->len);
  } else {
    jpg_chunking_t jchunk = {req, 0};
    res = frame2jpg_cb(fb, 80, jpg_encode_stream, &jchunk) ? ESP_OK : ESP_FAIL;
    httpd_resp_send_chunk(req, NULL, 0);
#if ARDUHAL_LOG_LEVEL >= ARDUHAL_LOG_LEVEL_INFO
    fb_len = jchunk.len;
#endif
  }
  esp_camera_fb_return(fb);
#if ARDUHAL_LOG_LEVEL >= ARDUHAL_LOG_LEVEL_INFO
  int64_t fr_end = esp_timer_get_time();
#endif
  log_i("JPG: %" PRIu32 "B %" PRId32 " ms", (uint32_t)fb_len, (int32_t)((fr_end - fr_start) / 1000));
  return res;
}
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

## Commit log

2026-05-18 Created repo and hardware test file to test ESP32 CAM MB
    [partitions.csv]
2026-05-19 finished esp32 testing and created first website verstion.
    esp32 is working good. website is still not connected to live stream.
2026-05-20 Successfully made the ESP32 its own router
2026-05-20 Made ESP32 its own wifi router and hosted its own website.
2026-05-21 Upgraded website.
    Added car controls, improved site, and improved communication between esp32 and device
2026-05-21 Upgraded website controls
    Included controls for brightness, contrast, and the LED (or headlights).
2026-05-23 Removed setup page, no longer needed.
    [app_httpd.cpp]
2026-05-27 Updated camera resolution, updated max LED brightness, and added a BOOT FLASH
2026-06-05 Updated the motor control login and added pic schematic
2026-06-09 Added code to test a single motor
2026-06-09 updated motor control logic
2026-06-24 Added assembly guide (completed) and 3d printed files
    [Camera_Mount.stl, T-Bracket_Mount.stl]
2026-06-29 updating main code by cleaning, adding clearer features, and fixing comments, moved also schematic and create a copy of last working ino file
2026-06-29 Rearranged files order and renamed
    [Camera_Mount.stl, T-Bracket_Mount.stl, partitions.csv]
2026-06-29 updated the naming of files.
    [Camera_Mount.stl, T-Bracket_Mount.stl]
2026-07-07 Updated the PCB files
    [esp32-cam-car.kicad_pcb, esp32-cam-car.kicad_sch]
2026-07-07 PCB files
2026-07-07 uploaded the zip files for the pcb files
    [esp32-cam-car.kicad_pcb, esp32-cam-car.kicad_sch]
